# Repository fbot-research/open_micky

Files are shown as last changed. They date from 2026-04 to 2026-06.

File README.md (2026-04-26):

# [Open MICKY🤖](https://open-micky.readthedocs.io/en/latest/)

 

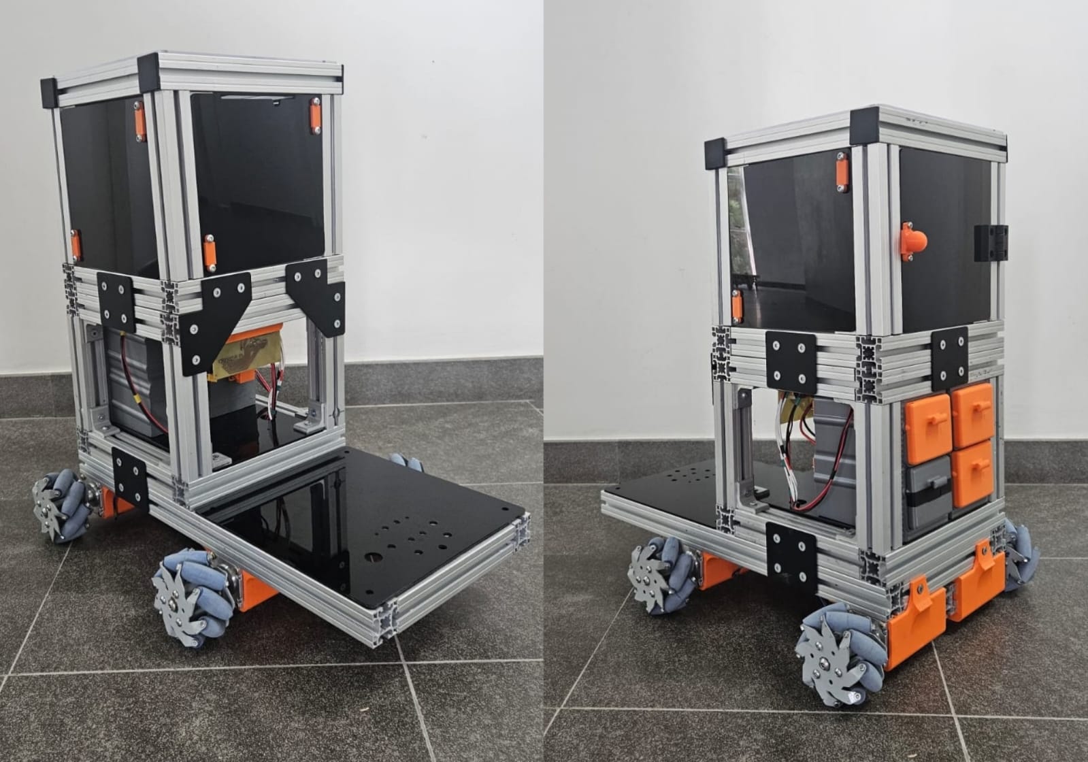
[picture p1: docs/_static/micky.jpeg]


 

---

## 💵 Total Cost 💵

> [!NOTE] 
> Cost excludes 3D printing, tools, shipping, and taxes.

| Price | BRL | EUR | USD |
|---|:---:|:---:|:---:|
| Structural Components | ~R$2103.18 | ~€458.66 | ~$1064.58 |
| Electrical System | ~R$902.4 | ~€406.47 | ~$200.81 |
| Locomotion System | ~R$2834.46 | ~€330.36 | ~$381.73 |
| **Total** | **~R$5840.04** | **~€1195.49** | **~$1647.12** |

---

## 🚀 Get Started 🚀

> [!NOTE] 
> If you are totally new to programming, please spend at least a day to get yourself familiar with basic Python, Ubuntu and Github (with the help of Google and AI). At least you should know how to setup ubuntu system, git clone, pip install, use intepreters (VS Code, Cursor, Pycharm, etc.) and directly run commands in the terminals.

1. 💵 **Buy your parts**: [Bill of Materials](https://open-micky.readthedocs.io/en/latest/hardware/getting_started/material.html)
2. 🖨️ **Print your parts**: [3D printing](https://open-micky.readthedocs.io/en/latest/hardware/getting_started/3d.html)
3. ⚒️ **Build your robot**: [Assembly](https://open-micky.readthedocs.io/en/latest/hardware/getting_started/assembly.html)
4. 💻 **Get it running**: [Software](https://open-micky.readthedocs.io/en/latest/software/index.html)

---

## 👥 Contributors

This project was developed by the FBOT Robotics Team.

**Main Contributors:**

- [Caio Paiva](https://github.com/CaioCPaiva) – Robot construction and 3D support design
- [Conrado Floriano](https://github.com/conradof) - Robot construction
- [Fernanda Oliveira](https://github.com/nanda0514) - Robot construction
- [Gabriel Torres](https://github.com/Gabrieltlt) - Documentation and website development
- [Henrique Vaz](https://github.com/Henrivaz) - Simulation development
- [Kauã Oliveira](https://github.com/KauaOliveira11) - Wheel control system and teleoperation
- [Patrick Meerssche](https://github.com/PatrickMeerssche) - Robot mechanical design
- [Pedro Paiva](https://github.com/pedromarchioretto) - Cost analysis

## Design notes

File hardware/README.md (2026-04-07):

# MICKY 3D Models

STL files for the Open MICKY robot.

---

## Upper Module



3D printed parts used in the robot's upper module.

---

## Lower Module



3D printed parts used in the robot's lower module.

---

## Base Module



3D printed parts used in the robot's base.

---

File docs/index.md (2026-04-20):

Open MICKY
===========

 

---

<div style="text-align: justify;">
  The high cost of commercial mobile robot platforms remains a significant barrier for teams entering competitive and research environments such as RoboCup@Work, particularly in regions with limited funding, such as Latin America. This barrier often restricts participation and slows down the development of new robotics solutions.

  MICKY was developed to address this challenge by providing a low-cost, open-source omnidirectional mobile base designed to be modular and mechanically capable. The platform follows a design philosophy similar to other accessible robotic bases, focusing on enabling new teams and researchers to enter the field of mobile robotics.

  The system adopts a modular architecture based on 40×40 T-slot aluminum extrusions combined with a Mecanum wheel drive system, enabling full holonomic motion while supporting significant payloads.
  
  Rather than relying on expensive proprietary solutions, MICKY is built using Commercial Off-The-Shelf (COTS) components and a simplified mechanical design. This approach enables a high payload-to-cost ratio while maintaining ease of assembly, maintenance, and customization.

  The platform is designed to support applications such as mobile manipulation, autonomous navigation, and robotics research, while allowing straightforward integration of sensors, actuators, and additional subsystems.

  Ultimately, MICKY aims to democratize access to mobile robotics by providing a scalable, reproducible, and economically viable platform for students, researchers, and robotics teams.
</div>



---

```{toctree}
:maxdepth: 2
:caption: Contents:

hardware/index
software/index
```

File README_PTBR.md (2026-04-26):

# [Open MICKY🤖](https://open-micky.readthedocs.io/en/latest/)

 



 

---

## 💵 Custo Total 💵

> [!NOTE] 
> O custo não inclui impressão 3D, ferramentas, frete e impostos.

| Preço | BRL | EUR | USD |
|---|:---:|:---:|:---:|
| Componentes Estruturais | ~R$2103.18 | ~€458.66 | ~$1064.58 |
| Sistema Elétrico | ~R$902.4 | ~€406.47 | ~$200.81 |
| Sistema de Locomoção | ~R$2834.46 | ~€330.36 | ~$381.73 |
| **Total** | **~R$5840.04** | **~€1195.49** | **~$1647.12** |

---

## 🚀 Começando 🚀

> [!NOTE] 
> Se você é totalmente iniciante em programação, recomendamos dedicar pelo menos um dia para se familiarizar com conceitos básicos de Python, Ubuntu e GitHub (com ajuda do Google ou ferramentas de IA). É importante saber configurar o sistema Ubuntu, utilizar comandos como `git clone` e `pip install`, usar ambientes de desenvolvimento (VS Code, Cursor, PyCharm, etc.) e executar comandos diretamente no terminal.

1. 💵 **Compre os componentes**: [Lista de Materiais](https://open-micky.readthedocs.io/pt-br/latest/hardware/getting_started/material.html)
2. 🖨️ **Imprima as peças**: [Impressão 3D](https://open-micky.readthedocs.io/pt-br/latest/hardware/getting_started/3d.html)
3. 🛠️ **Monte o robô**: [Montagem](https://open-micky.readthedocs.io/pt-br/latest/hardware/getting_started/assembly.html)
4. 💻 **Coloque em funcionamento**: [Software](https://open-micky.readthedocs.io/pt-br/latest/software/index.html)

---

## 👥 Contribuidores

Este projeto foi desenvolvido pela equipe de robótica FBOT.

**Principais Contribuidores:**

- [Caio Paiva](https://github.com/CaioCPaiva) – Construção do robô e modelagem dos suportes 3D  
- [Conrado Floriano](https://github.com/conradof) – Construção do robô  
- [Fernanda Oliveira](https://github.com/nanda0514) – Construção do robô  
- [Gabriel Torres](https://github.com/Gabrieltlt) – Documentação e desenvolvimento do site  
- [Henrique Vaz](https://github.com/Henrivaz) – Desenvolvimento da simulação  
- [Kauã Oliveira](https://github.com/KauaOliveira11) – Sistema de controle das rodas e teleoperação  
- [Patrick Meerssche](https://github.com/PatrickMeerssche) – Projeto mecânico do robô  
- [Pedro Paiva](https://github.com/pedromarchioretto) – Análise de custos

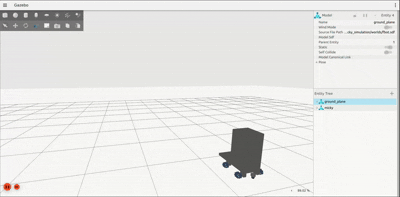
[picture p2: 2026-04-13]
docs/_static/videos/simulation_video.gif

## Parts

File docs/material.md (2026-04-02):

#  **Bill of Material**

##  Total Cost 

```{note}
Doesn't include cost of 3D printing, tools, shipping and taxes.
```

| Price | R$ | US | EU |
| --- | --- | --- | --- |
| Structural | ~R$949.62 | ~$184.16 | ~€158.78 |
| Motion System | ~R$3140 | ~$608.95 | ~€525.01 |
| Eletronics | ~R$1133.01 | ~$219.73 | ~€189.44 |
| **Total** | **~R$5222.63** | **~$1012.84** | **~€873.22** |

## Structural

| Part | Amount | Unit Cost (R$) | Buy (R$) |
| --- | --- | --- | --- |
| Placa Quadrada p/ Perfil Base 40 | 3 | ~R$17.46 | [Forseti](https://loja.forsetisolucoes.com.br/placa-de-conexao-montagem-lateral-quadrada-para-perfil-estrutural-em-aluminio) |
| Placa de Conexão T p/ Perfil Base 40 | 3 | ~R$26.78 | [Forseti](https://loja.forsetisolucoes.com.br/placa-de-conexao-montagem-t-para-perfil-estrutural-em-aluminio) |
| Porca Martelo Canal 8 - p/ Perfil Base 40 - M6 - 50un | 1 | ~R$83.16 | [Forseti](https://loja.forsetisolucoes.com.br/porca-t-martelo-para-perfil-estrututral-em-aluminio-canal-8-40-40x40-tslot-t-slot) |
| Placa de Conexão 90° - c/ Corte p/ Perfil 40 | 6 | ~R$27.94 | [Forseti](https://loja.forsetisolucoes.com.br/placa-de-conexao-montagem-90-graus-com-corte-para-perfil-estrutural-em-aluminio) |
| Perfil estrutural 40x40mm - CANAL 8 - 300mm | 6 | ~R$33.3 | [Forseti](https://loja.forsetisolucoes.com.br/perfil-estrutural-em-aluminio-40x40-basico-canal-8-t-slot-tslot) |
| Perfil estrutural 40x40mm CANAL 8 - 220mm | 15 | ~R$24.42 | [Forseti](https://loja.forsetisolucoes.com.br/perfil-estrutural-em-aluminio-40x40-basico-canal-8-t-slot-tslot) |

## Motion System

| Part | Amount | Unit Cost (R$) | Buy (R$) |
| --- | --- | --- | --- |
| Driver para Motor de Passo TB6600 | 6 | ~R$75 | [Robocore](https://www.robocore.net/driver-motor/driver-para-motor-de-passo-tb6600) |
| Motor de Passo Nema 23 – Torque 30 kgf (EIXO 21mm x 8mm) | 6 | ~R$215 | [Tecmaf](https://loja.tecmaf.com.br/motores-de-passo-e-componentes-cnc/motor-de-passo/motor-de-passo-nema-23-30kgf-cm-749) |
| Conjunto de Rodas Mecanum MEC-100 | 1 | ~R$1400 | [Celusinagem](https://celusinagem.wixsite.com/omni-mecanum) |

```{note}
We opted to manufacture the wheels through a local supplier, as this proved to be significantly more profitable than purchasing them online.
```

## Electronics

| Part | Amount | Unit Cost (R$) | Unit Cost (US) | Unit Cost (EU) | Buy (R$) |
| --- | --- | --- | --- | --- | --- |
| 5-Conductor Lever-Nut Connector | 10 | R$3.50 | $0.68 | €0.59 | [Eletrogate](https://www.eletrogate.com/conector-wago-borne-emenda-para-5-fios) |
| XT60 60A Male/Female Power Connector Pair | 8 | R$6.70 | $1.28| €1.11 | [Eletrogate](https://www.eletrogate.com/conector-xt-60) |
| Heat Shrink Tubing Assortment Kit, 5 Colors, 328 Pieces | 1 | R$14.90 | $2.89 | €2.49 | [Eletrogate](https://www.eletrogate.com/kit-tubo-termo-retratil-com-328-unidades-em-5-cores) |
| Nickel-Plated Steel Strip for 18650 Battery Spot Welding (10 m × 8 mm)| 5 | R$30.93 | $6.00 | €5.18 | [Usainfo](https://www.usinainfo.com.br/ferramentas/fita-de-niquel-com-aco-para-soldar-baterias-18650-10-metros-x-8mm-8694.html) |
| Insulated Fork Terminals for 2.5 mm² Conductors (Blue, 100 pcs)| 1 | R$31.00 | $6.01 | €5.19 | [Casa do Eletricista](https://www.casadoeletricistasc.com.br/terminal-pre-isolado-garfo-para-cabo-2-5mm2-azul-100-unidades/p/kit197) |
| TP-Link UH700 7-Port USB 3.0 Powered Hub | 1 | R$229.90 | $44.6 | €38.49 | [Kabum](https://www.kabum.com.br/produto/129463/hub-tp-link-portatil-usb-3-0-de-7-portas-uh700) |

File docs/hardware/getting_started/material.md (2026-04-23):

# 🛒 Bill of Materials

<div style="text-align: justify;">

## Total Cost 

```{note}
Doesn't include cost of 3D printing, tools, shipping and taxes.
```

| Price | BRL | EUR | USD |
|---|:---:|:---:|:---:|
| Structural Components | ~R$2103.18 | ~€458.66 | ~$1064.58 |
| Electrical System | ~R$902.4 | ~€406.47 | ~$200.81 |
| Locomotion System | ~R$2834.46 | ~€330.36 | ~$381.73 |
| **Total** | **~R$5840.04** | **~€1195.49** | **~$1647.12** |

---

## Structural Components

| Part | Amount | Unit Cost (BRL) | Buy (R$) | Unit Cost (EUR) | Buy (€) | Unit Cost (USD) | Buy ($) |
|---|:---:|:---:|:---:|:---:|:---:|:---:|:---:|
| 40×40 T-Slot Aluminum Extrusion 600 mm | 2 | ~R$75.60 | [Forseti](https://loja.forsetisolucoes.com.br/perfil-estrutural-em-aluminio-40x40-basico-canal-8-t-slot-tslot) | ~€8.58 | [Motedis](https://www.motedis.com/en/Profile-40x40L-I-Type-slot-8) | ~$33.60 | [McMASTER-CARR](https://www.mcmaster.com/products/aluminum-extrusions/rail-height~40-mm/t-slotted-framing-rails-4/) |
| 40×40 T-Slot Aluminum Extrusion 300 mm | 8 | ~R$37.80 | [Forseti](https://loja.forsetisolucoes.com.br/perfil-estrutural-em-aluminio-40x40-basico-canal-8-t-slot-tslot) | ~€4.29 | [Motedis](https://www.motedis.com/en/Profile-40x40L-I-Type-slot-8) | ~$16.80 | [McMASTER-CARR](https://www.mcmaster.com/products/aluminum-extrusions/rail-height~40-mm/t-slotted-framing-rails-4/) |
| 40×40 T-Slot Aluminum Extrusion 220 mm | 15 | ~R$27.72 | [Forseti](https://loja.forsetisolucoes.com.br/perfil-estrutural-em-aluminio-40x40-basico-canal-8-t-slot-tslot) | ~€3.37 | [Motedis](https://www.motedis.com/en/Profile-40x40L-I-Type-slot-8) | ~$12.32 | [McMASTER-CARR](https://www.mcmaster.com/products/aluminum-extrusions/rail-height~40-mm/t-slotted-framing-rails-4/) |
| 40×40 T-Slot Aluminum Extrusion 180 mm | 4 | ~R$22.68 | [Forseti](https://loja.forsetisolucoes.com.br/perfil-estrutural-em-aluminio-40x40-basico-canal-8-t-slot-tslot) | ~€2.76 | [Motedis](https://www.motedis.com/en/Profile-40x40L-I-Type-slot-8) | ~$10.08 | [McMASTER-CARR](https://www.mcmaster.com/products/aluminum-extrusions/rail-height~40-mm/t-slotted-framing-rails-4/) |
| 40×40 T-Slot Aluminum Extrusion 75 mm | 2 | ~R$10.08 | [Forseti](https://loja.forsetisolucoes.com.br/perfil-estrutural-em-aluminio-40x40-basico-canal-8-t-slot-tslot) | ~€1.15 | [Motedis](https://www.motedis.com/en/Profile-40x40L-I-Type-slot-8) | ~$4.20 | [McMASTER-CARR](https://www.mcmaster.com/products/aluminum-extrusions/rail-height~40-mm/t-slotted-framing-rails-4/) |
| L-Bracket | 38 | ~R$4.77 | [Forseti](https://loja.forsetisolucoes.com.br/cantoneira-38x38x28mm-em-aluminio-p-perfis-base-30-40-45-50-t-slot-tslot) | ~€1.10 | [Motedis](https://www.motedis.com/en/Bracket-Alu-anodized-40x40) | ~$5.14 | [80/20](https://8020.net/40-4302.html) |
| Profile End Cap | 18 | ~R$2.47 | [Forseti](https://loja.forsetisolucoes.com.br/capa-de-fechamento-frontal-quadrada-preta-para-perfil-estrutural-em-aluminio) | ~€0.47 | [Motedis](https://www.motedis.com/en/Cover-Caps-40x40-I-Type-Slot-8) | ~$0.76 | [Motedis-USA](https://www.motedis-usa.com/en/Cover-Caps-40x40-I-Type-Slot-8) |
| Square Connector Plate 40×40 | 3 | ~R$10.95 | [Forseti](https://loja.forsetisolucoes.com.br/placa-de-conexao-montagem-lateral-quadrada-para-perfil-estrutural-em-aluminio) | ~€2.57 | [Motedis](https://www.motedis.com/en/Square-connector-plate-76x76x5-Lasercut) | ~$4.17 | [Motedis-USA](https://www.motedis-usa.com/en/Square-connector-plate-76x76x5-Lasercut) |
| L Connector Plate 40×40 | 2 | ~R$21.27 | [Forseti](https://loja.forsetisolucoes.com.br/placa-de-conexao-montagem-90-graus-com-corte-para-perfil-estrutural-em-aluminio) | ~€3.82 | [Motedis](https://www.motedis.com/en/-L-connector-plate-Alu-elox-4040) | ~$6.21 | [Motedis-USA](https://www.motedis-usa.com/en/-L-connector-plate-Alu-elox-4040?show_cart=1&from_cart=1&products_id=9999910079) |
| T Connector Plate 40×40 | 1 | ~R$13.15 | [Forseti](https://loja.forsetisolucoes.com.br/placa-de-conexao-montagem-t-para-perfil-estrutural-em-aluminio) | ~€4.49 | [Motedis](https://www.motedis.com/en/Connector-plate-T-Alu-elox-4040) | ~$7.29 | [Motedis-USA](https://www.motedis-usa.com/en/Connector-plate-T-Alu-elox-4040) |
| M6 x 12 mm Countersunk Allen Screw | 160 | ~R$0.86 | [Forseti](https://loja.forsetisolucoes.com.br/parafuso-allen-cabeca-conica-escareada-m6) | ~€0.34 | [Motedis](https://www.motedis.com/en/countersunk-screw-with-hexagon-socket-according-to-DIN-7991) | ~$0.63 | [80/20](https://8020.net/13-6712.html) |
| M6 x 20 mm Countersunk Allen Screw | 4 | ~R$0.86 | [Forseti](https://loja.forsetisolucoes.com.br/parafuso-allen-cabeca-conica-escareada-m6) | ~€0.33 | [Motedis](https://www.motedis.com/en/countersunk-screw-with-hexagon-socket-according-to-DIN-7991) | ~$0.85 | [80/20](https://8020.net/11-6720.html) |
| M4 x 20 mm Countersunk Allen Screw | 12 | ~R$0.32 | [Parafuso Fácil](https://www.parafusofacil.com.br/parafuso-allen/parafuso-allen-chato/din-7991-parafuso-allen-chato-ma-4-x-20-inox-304-a2-classe-70-passivado/) | ~€0.32 | [Motedis](https://www.motedis.com/en/countersunk-screw-with-hexagon-socket-according-to-DIN-7991) | ~$0.52 | [Motedis-USA](https://www.motedis-usa.com/en/countersunk-screw-with-hexagon-socket-according-to-DIN-7991) |
| M4 x 12 mm Countersunk Allen Screw | 18 | ~R$0.11| [Parafuso Fácil](https://www.parafusofacil.com.br/parafuso-allen/parafuso-allen-chato/din-7991-parafuso-allen-chato-ma-4-x-12-aco-liga-classe-10-9-enegrecido-de-tempera-1/) | ~€0.32 | [Motedis](https://www.motedis.com/en/countersunk-screw-with-hexagon-socket-according-to-DIN-7991) | ~$0.69 | [80/20](https://8020.net/11-4712.html) |
| M6 x 35 mm Motor Mount Screw | 16 | ~R$1.72 | [Forseti](https://loja.forsetisolucoes.com.br/parafuso-allen-cabeca-abaulada-panela-m6) | ~€0.39 | [Motedis](https://www.motedis.com/en/countersunk-screw-with-hexagon-socket-according-to-DIN-7991) | ~$0.63 | [Motedis-USA](https://www.motedis-usa.com/en/countersunk-screw-with-hexagon-socket-according-to-DIN-7991) |
| M6 T-Nut | 130 | ~R$2.08 | [Forseti](https://loja.forsetisolucoes.com.br/porca-t-martelo-para-perfil-estrututral-em-aluminio-canal-8-40-40x40-tslot-t-slot) | ~€0.50 | [Motedis](https://www.motedis.com/en/T-nut-B-type-slot-8-M6-stainless-steel) | ~$1.19 | [80/20](https://8020.net/13119.html) |
| M6 Hex Nut | 34 | ~R$0.57 | [Forseti](https://loja.forsetisolucoes.com.br/porca-sextavada-m3-m4-m5-m6-m8-m10-m12) | ~€0.30 | [Motedis](https://www.motedis.com/en/Nut-DIN-439-M4-M5-M6-M8-M10-and-M12) | ~$0.14 | [80/20](https://8020.net/3820.html) |
| M4 Hex Nut | 56 | ~R$0.57 | [Forseti](https://loja.forsetisolucoes.com.br/porca-sextavada-m3-m4-m5-m6-m8-m10-m12) | ~€0.30 | [Motedis](https://www.motedis.com/en/Nut-DIN-439-M4-M5-M6-M8-M10-and-M12) | ~$0.19 | [80/20](https://8020.net/11-4065.html) |
| Copper Sheet 30 × 20 cm | 2 | ~R$29.70 | [UsinaInfo](https://www.usinainfo.com.br/placa-de-fenolite/placa-de-fenolite-cobreada-simples-15x30-cm-para-circuito-impresso-3845.html) | ~€11.65 | [LinGold](https://lingold.pt/copper-sheet/copper-sheet-15-mm) | ~$5.20 | [MCTInfo](https://mctinfo.net/products/copper-clad-laminate-fr4) |
| Acrylic Sheet 1 m × 1.3 m | 1 | ~R$253.16 | [AcriLoja](https://www.acriloja.com/placa-chapa-acrilico/preto/2mm/placa-de-acrilico-preto-100cm-x-150cm-espessura-2mm-chapa-de-acrilico) | ~€86.33 | [Plastic Sheets Shop](https://plasticsheetsshop.co.uk/product/frosted-black-acrylic-sheet-3-mm/) | ~$74.80 | [ACPlasticsInc](https://www.acplasticsinc.com/products/2025-060-48x-72-trucast-p) |

---

## Electrical System

| Part | Amount | Unit Cost (BRL) | Buy (R$) | Unit Cost (EUR) | Buy (€) | Unit Cost (USD) | Buy ($) |
|---|:---:|:---:|:---:|:---:|:---:|:---:|:---:|
| Hoverboard Battery (36V) | 4 | ~R$139.30 | [Arco Iris LED](https://www.arcoirisled.com.br/produto/bateria-original-para-hoverboard-eletrico-36v-44ah-ydtech) | ~€89.99 | [Decathlon](https://www.decathlon.ie/p/1100365324-2495102-36v-4ah-hoverboard-battery-replacement.html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) | ~$44.99 | [BatteryGC](https://batterygc.com/products/10s2p-36v-4-4ah-18650-li-ion-battery-for-hoverboard-scooter-balance-board-car) |
| Ferrule Terminals (Wire Ferrules) | 20 | ~R$14.69 | [Santil](https://www.santil.com.br/terminal-ilhos-pre-isolado-cinza-simples-4mm-com-100-pecas-eletrokit/p) | ~€0.086 | [Mouser](https://eu.mouser.com/ProductDetail/KS-Terminals/EN2508?qs=%252B6g0mu59x7IZJehitj7%252BJA%3D%3D) | ~$0.014 | [FerrulesDirect](https://www.ferrulesdirect.com/collections/insulated-wire-ferrules/products/ad15006) |
| 20A Switch | 3 | ~R$7.50 | [Casa do Resistor](https://www.casadoresistor.com.br/chave-kcd4-201-4t-16-20a-125-250v-preta) | ~€5.6 | [Hestore](https://www.hestore.eu/prod_10040377.html#) | ~$3.15 | [McMASTRER-CARR](https://www.mcmaster.com/products/7395k111/) |
| Emergency Stop Button (Mushroom Type) | 1 | ~R$28.90 | [OnEletrica](https://www.oneletrica.com.br/botao-emergencia-22mm-gira-destrava-com-2-contatos-nf) | ~€27.99 | [Conrad](https://www.conrad.com/en/p/schneider-electric-xb5as8442-kill-switch-epo-switch-front-ring-steel-kill-switch-round-reset-function-lockable-1-1983552.html) | ~$11.12 | [RS](https://us.rs-online.com/product/altech-corp/2am4/70156810/) |

```{important}
Use a 2 mm² flexible cable (approximately AWG 14) for power distribution.
```

---

## Locomotion System

| Part | Amount | Unit Cost (BRL) | Buy (R$) | Unit Cost (EUR) | Buy (€) | Unit Cost (USD) | Buy ($) |
|---|:---:|:---:|:---:|:---:|:---:|:---:|:---:|
| NEMA 23 Stepper Motor (30 kgf·cm) | 4 | ~R$215.00 | [Tecmaf](https://loja.tecmaf.com.br/motores-de-passo-e-componentes-cnc/motor-de-passo/motor-de-passo-nema-23-30kgf-cm-749) | ~€21.24 | [Cloudray](https://www.cloudraylaser.com/products/cloudray-102mm-3n-m-5a-2-phase-nema23-open-loop-stepper-motor) | ~$28.70 | [StepperOnline](https://www.omc-stepperonline.com/nema-23-bipolar-3nm-425oz-in-8mm-diameter-4-2a-57x57x113mm-4-wires-stepper-motor-23hs45-4204s1) |
| TB6600 Stepper Driver | 4 | ~R$79.90 | [RoboCore](https://www.robocore.net/driver-motor/driver-para-motor-de-passo-tb6600) | ~€11.95 | [Otronic](https://www.otronic.nl/en/tb6600-stepper-motor-driver-for-nema-17-23-34-9-42.html) | ~$20.00 | [DFRobot](https://www.dfrobot.com/product-1547.html) |
| MPU-9250 IMU with BMP280 (6-pin) | 2 | ~R$127.43 | [Elecbee](https://www.elecbee.com/en/product-detail/mpu9250-bmp280-10dof-gy-91-acceleration-gyroscope-compass-nine-shaft-sensor-module_25515) | ~€22.89 | [Elecbee](https://www.elecbee.com/en/product-detail/mpu9250-bmp280-10dof-gy-91-acceleration-gyroscope-compass-nine-shaft-sensor-module_25515) | ~$23.38 | [Elecbee](https://www.elecbee.com/en/product-detail/mpu9250-bmp280-10dof-gy-91-acceleration-gyroscope-compass-nine-shaft-sensor-module_25515) |
| 100mm Mecanum Wheel | 1 | ~R$1400.00 | [CelUsinagem](https://celusinagem.wixsite.com/omni-mecanum) | ~€151.82 | [RobotShop](https://eu.robotshop.com/products/100mm-mecanum-wheel-set) | ~$140.17 | [RobotShop](https://www.robotshop.com/products/100mm-mecanum-wheel-set) |

```{note}
We opted to manufacture the wheels through a local supplier, as this proved to be significantly more cost-effective than purchasing them online. For reference, links to similar wheels available on the market are provided above.
```

---

## 3D Printed Parts

The following table lists all required 3D printed components.

| Module | Part | Quantity | STL Link |
|---|:----:|:---:|:---:|
| Structural | Door Handle| 1 | [STL](https://github.com/fbot-research/open_micky/blob/main/hardware/structural/door_handle.stl) |
| Structural | Door Handle Magnet | 1 | [STL](https://github.com/fbot-research/open_micky/blob/main/hardware/structural/door_handle_magnet.stl) |
| Structural | Side Acrylic Magnet | 6 | [STL](https://github.com/fbot-research/open_micky/blob/main/hardware/structural/side_acrylic_magnet.stl) |
| Structural | Side Acrylic Magnet Mount | 6 | [STL](https://github.com/fbot-research/open_micky/blob/main/hardware/structural/side_acrylic_magnet_mount.stl) |
| Battery | Battery Case Lower | 4 | [STL](https://github.com/fbot-research/open_micky/blob/main/hardware/battery/battery_case_female_socket_mount.stl) |
| Battery | Battery Case Upper | 4 | [STL](https://github.com/fbot-research/open_micky/blob/main/hardware/battery/battery_case_lower.stl) |
| Battery | Battery Case Female Socket Mount | 4 | [STL](https://github.com/fbot-research/open_micky/blob/main/hardware/battery/battery_case_upper.stl) |
| Battery | Battery Hotswap Connector | 2 | [STL](https://github.com/fbot-research/open_micky/blob/main/hardware/battery/battery_hotswap_connector.stl) |
| Battery | Battery Hotswap Male Connector | 4 | [STL](https://github.com/fbot-research/open_micky/blob/main/hardware/battery/battery_hotswap_male_connector.stl) |
| Drivers | Arduino Board Mount | 1 | [STL](https://github.com/fbot-research/open_micky/blob/main/hardware/drivers/arduino_PCB_support.stl) |
| Drivers | Driver Board Left Mount | 1 | [STL](https://github.com/fbot-research/open_micky/blob/main/hardware/drivers/driver_PCB_left_support.stl) |
| Drivers | Driver Board Right Mount | 1 | [STL](https://github.com/fbot-research/open_micky/blob/main/hardware/drivers/driver_PCB_right_support.stl) |
| Drivers | PCB's Support | 1 | [STL](https://github.com/fbot-research/open_micky/blob/main/hardware/drivers/PCBs_support.stl) |
| Drivers | Drivers Mount | 4 | [STL](https://github.com/fbot-research/open_micky/blob/main/hardware/drivers/drivers_support.stl) |
| Motors | Front Motor Mount | 2 | [STL](https://github.com/fbot-research/open_micky/blob/main/hardware/motors/front_motor_mount.stl) |
| Motors | Rear Motor Mount Left | 1 | [STL](https://github.com/fbot-research/open_micky/blob/main/hardware/motors/rear_motor_mount_left.stl) |
| Motors | Rear Motor Mount Right | 1 | [STL](https://github.com/fbot-research/open_micky/blob/main/hardware/motors/rear_motor_mount_right.stl) |
| Emergency | Emergency Stop Button Mount | 1 | [STL](https://github.com/fbot-research/open_micky/blob/main/hardware/emergency_button/emergency_button.stl) |

</div>

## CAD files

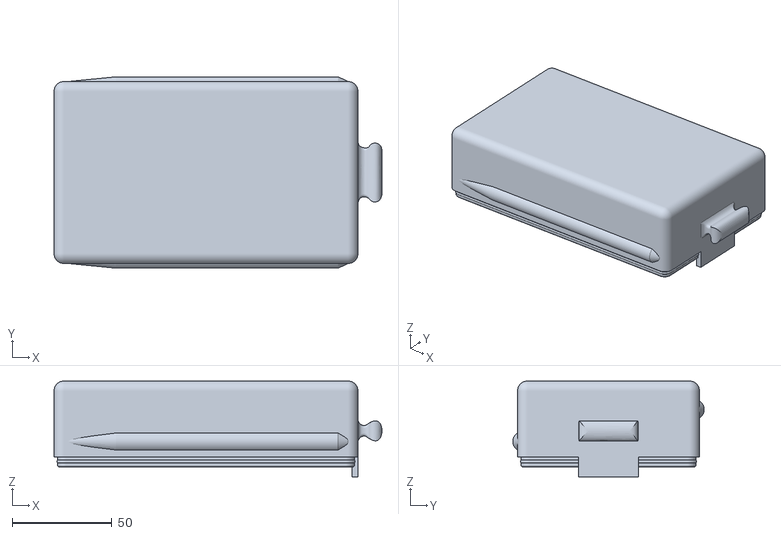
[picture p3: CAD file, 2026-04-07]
hardware/battery/battery_case_upper.stl
164.0 x 95.7 x 48.0

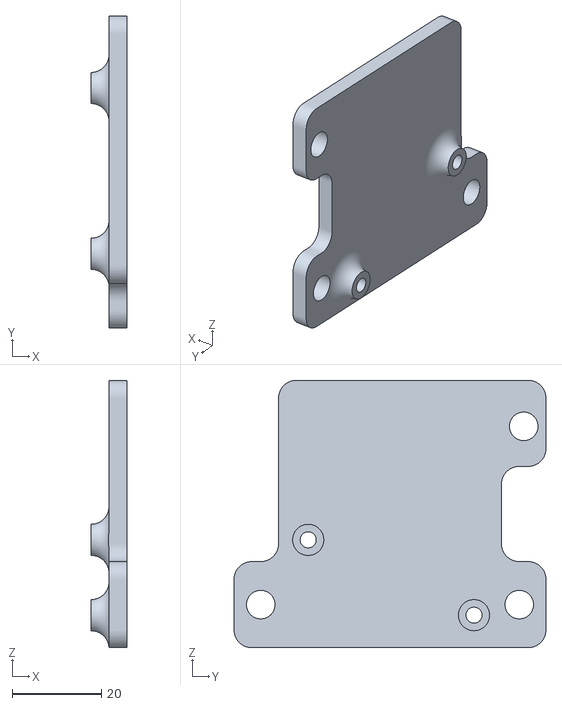
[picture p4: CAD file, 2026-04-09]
hardware/drivers/driver_PCB_left_support.stl
8.00 x 70.0 x 60.0

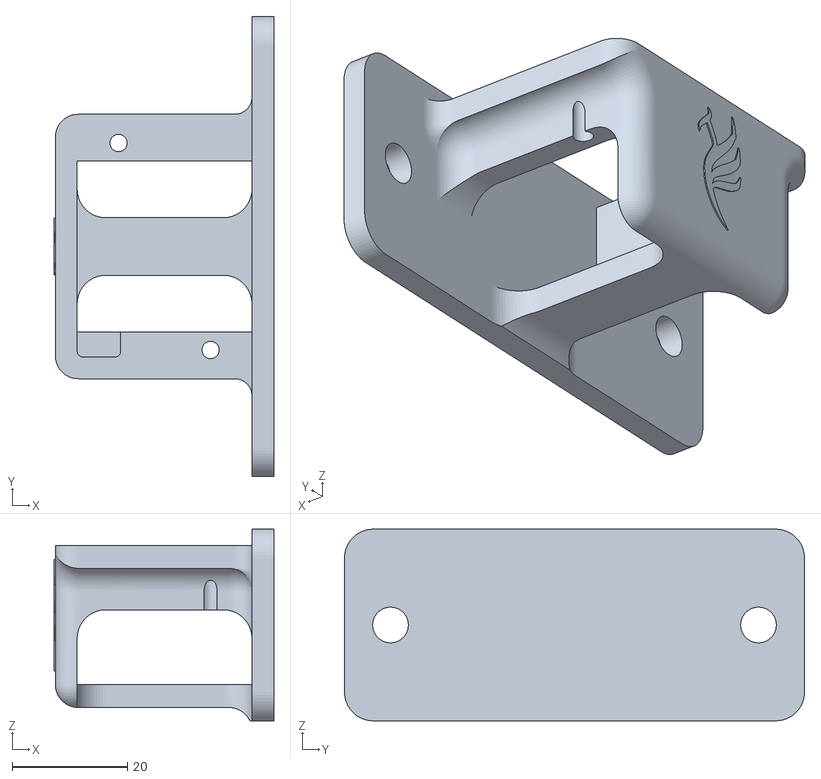
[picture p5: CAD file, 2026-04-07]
hardware/emergency_button/emergency_button.stl
38.2 x 80.0 x 33.3

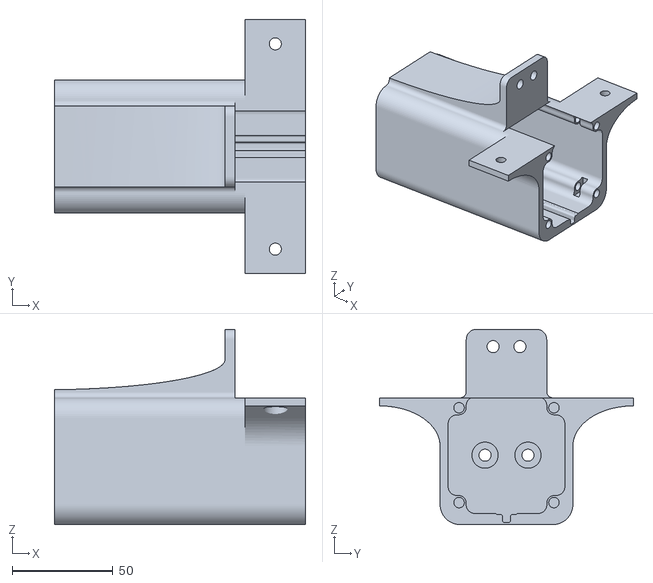
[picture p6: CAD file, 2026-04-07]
hardware/motors/front_motor_mount.stl
124.7 x 126.0 x 97.0

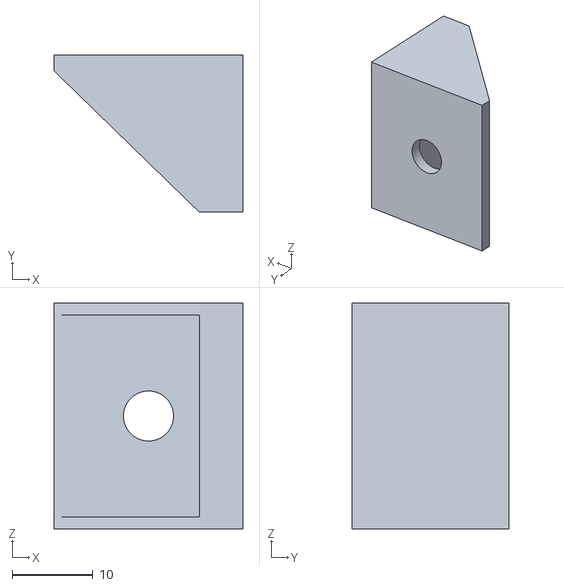
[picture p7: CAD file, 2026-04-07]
hardware/structural/side_acrylic_magnet.stl
23.4 x 19.5 x 28.0

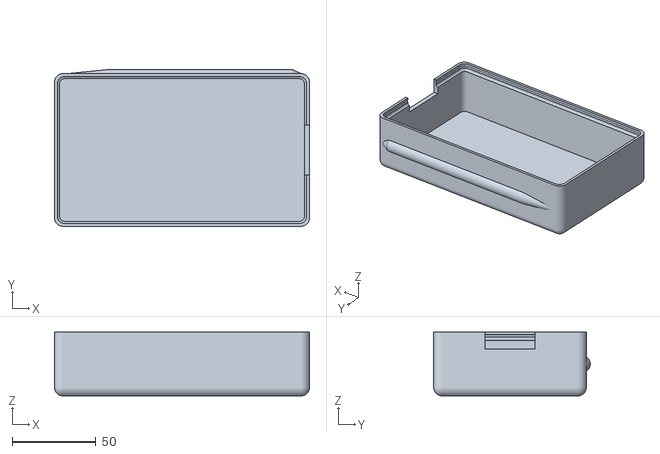
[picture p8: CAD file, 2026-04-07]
hardware/battery/battery_case_lower.stl
152.0 x 93.4 x 38.0

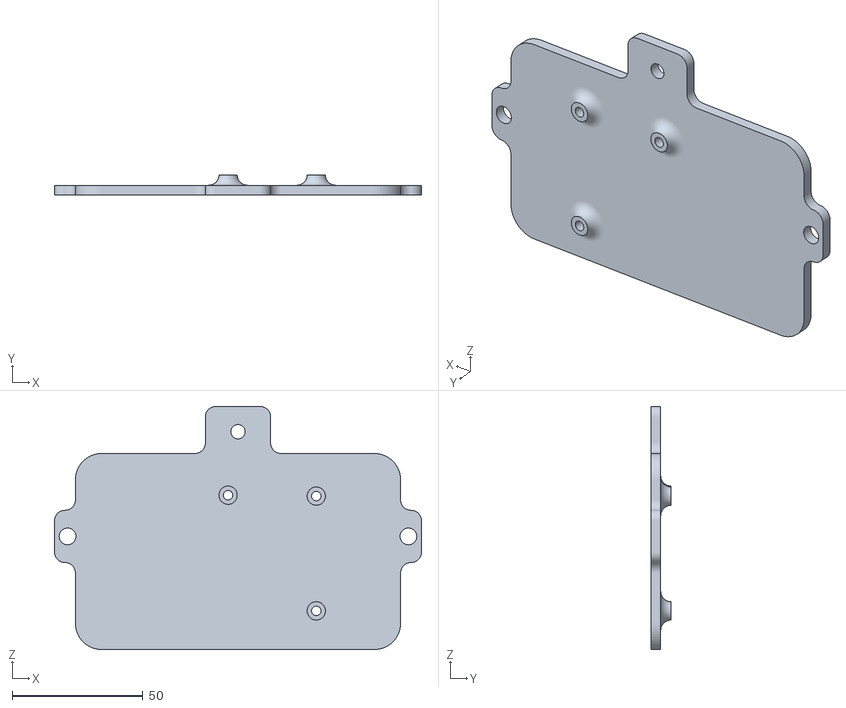
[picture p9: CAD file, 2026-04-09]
hardware/drivers/arduino_PCB_support.stl
140.4 x 7.80 x 93.0

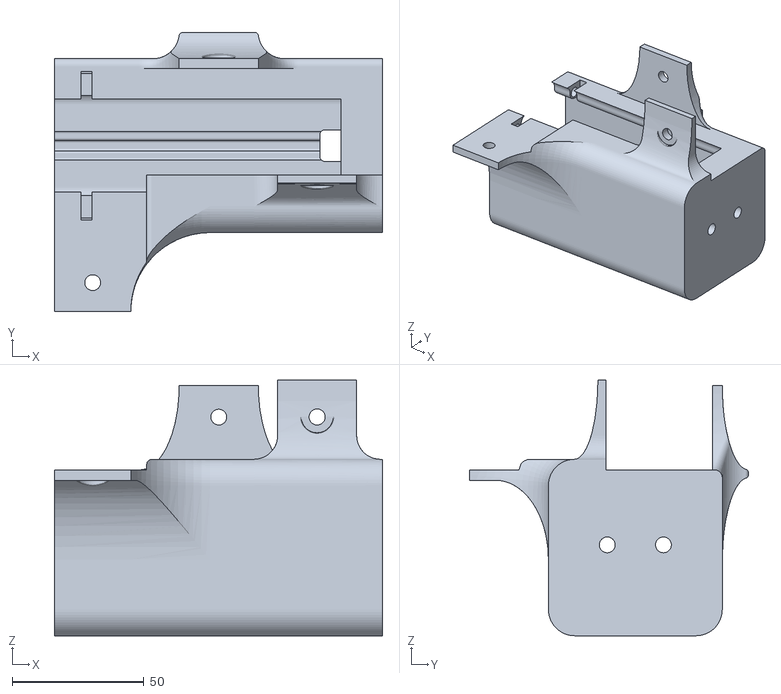
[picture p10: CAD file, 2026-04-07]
hardware/motors/rear_motor_mount_right.stl
124.5 x 106.0 x 97.0

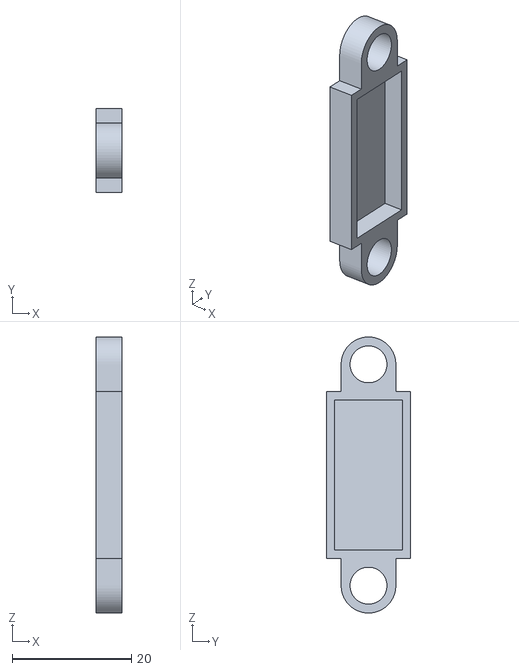
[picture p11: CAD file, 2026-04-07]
hardware/structural/side_acrylic_magnet_mount.stl
4.30 x 14.2 x 46.4

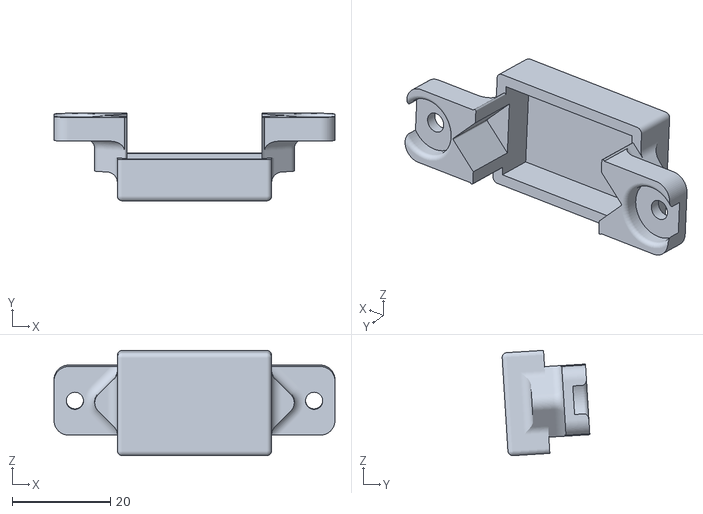
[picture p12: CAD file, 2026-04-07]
hardware/battery/battery_hotswap_male_connector.stl
57.2 x 17.8 x 21.4

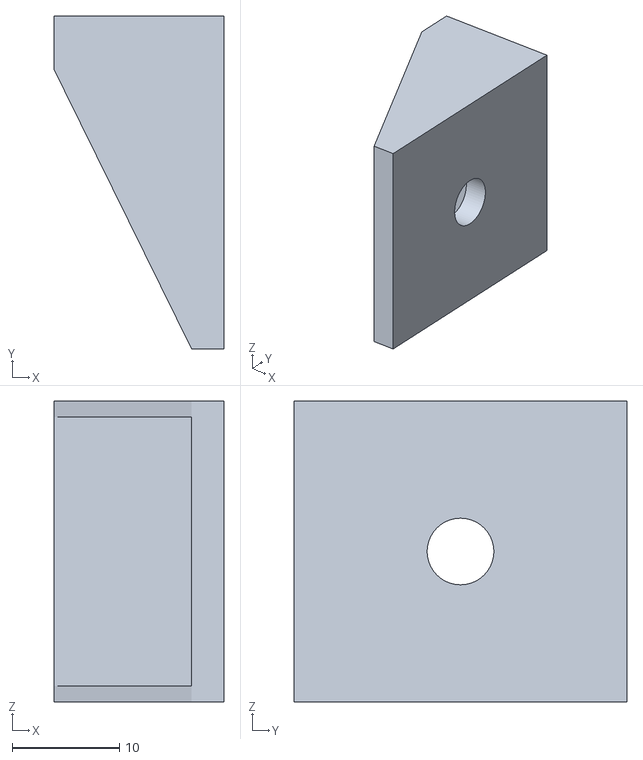
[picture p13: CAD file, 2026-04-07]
hardware/structural/door_handle_magnet.stl
15.8 x 31.0 x 28.0

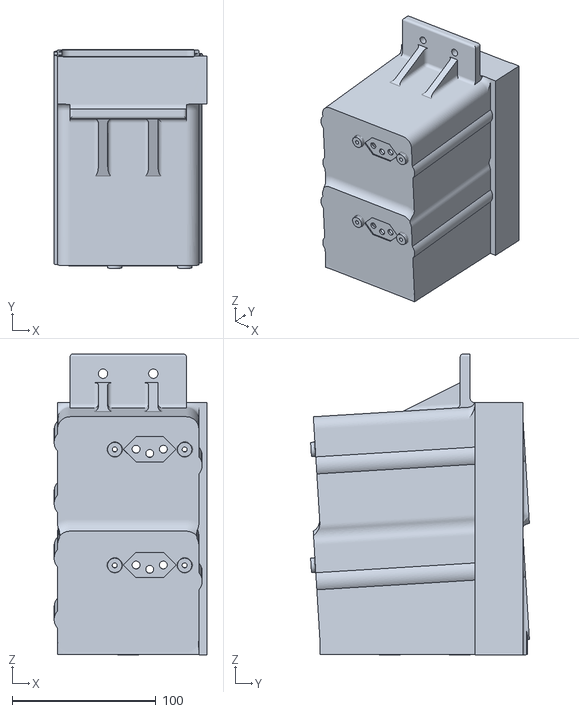
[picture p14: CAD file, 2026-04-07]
hardware/battery/battery_hotswap_connector.stl
106.4 x 152.4 x 209.7

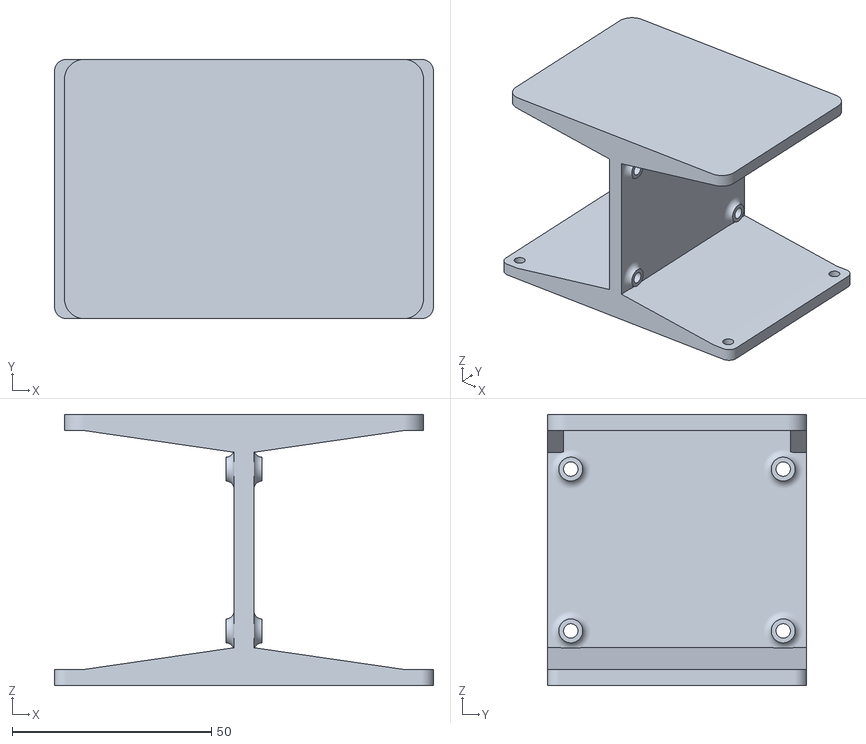
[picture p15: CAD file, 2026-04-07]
hardware/drivers/PCBs_support.stl
95.0 x 65.0 x 68.0

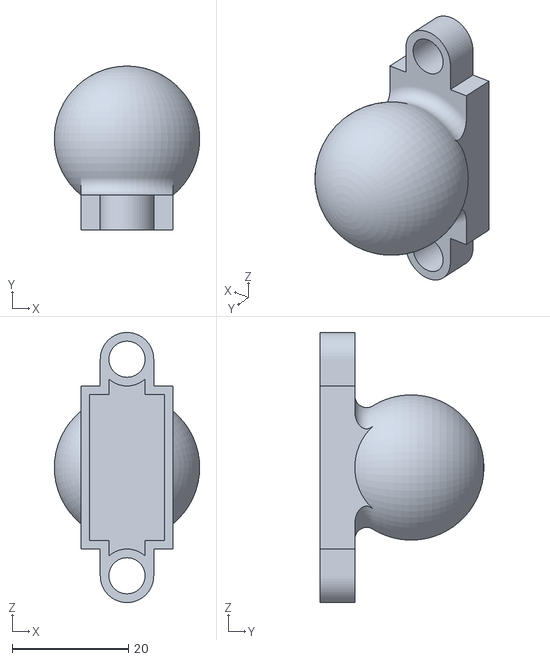
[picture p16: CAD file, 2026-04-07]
hardware/structural/door_handle.stl
25.0 x 28.2 x 46.4

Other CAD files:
hardware/drivers/driver_PCB_right_support.stl
hardware/motors/rear_motor_mount_left.stl
hardware/battery/battery_case_female_socket_mount.stl
hardware/drivers/drivers_support.stl

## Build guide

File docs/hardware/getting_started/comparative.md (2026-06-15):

# 📊 Comparative Analysis

<div style="text-align: justify;">

## Introduction

The development of low-cost and accessible robotic platforms remains a critical challenge for teams entering competitive and research-oriented environments such as RoboCup@Industrial, particularly in regions with limited funding such as Latin America. High costs associated with commercial mobile bases often create a significant barrier to entry, restricting participation and slowing down innovation.

In this context, we present the MICKY mobile base, an omnidirectional robotic platform specifically designed to reduce this barrier by prioritizing cost-efficiency without compromising mechanical capability. The platform adopts a modular architecture based on industrial 40x40 mm aluminum profiles and a Mecanum wheel drive system, enabling holonomic motion and supporting substantial payloads.

Rather than relying on expensive proprietary solutions, MICKY is built using Commercial Off-The-Shelf (COTS) components and a simplified mechanical design. This approach allows the platform to achieve a high payload-to-cost ratio while remaining accessible, maintainable, and adaptable to different use cases.

The system is designed to support mobile manipulation, autonomous navigation, and general-purpose robotics research, while allowing straightforward integration of sensors, actuators, and additional subsystems. Its modularity ensures that the platform can evolve according to the needs of each team.

This work also presents a comparative analysis between MICKY and other omnidirectional mobile bases, emphasizing its efficiency in terms of cost versus payload. The results highlight its position as a competitive and accessible alternative for teams seeking high mechanical performance under budget constraints.

Ultimately, the goal of this project is to democratize access to mobile robotics by providing a scalable, reproducible, and economically viable platform for new teams and researchers.

---

## 1. Technical Characterization of the MICKY Base

The MICKY base features a structure built from industrial 40×40 mm aluminum profiles combined with a Mecanum wheel drive system. Although the hardware includes six motors, the control architecture utilizes four active motors for locomotion.

To provide transparency regarding the platform's cost-efficiency, the total Bill of Materials (BOM) is broken down by functional subsystem in Table 1. 

**Table 1: Detailed Component Cost Breakdown**

| Subsystem | Components | Estimated Cost (USD) |
| :--- | :--- | :--- |
| **Structural** | 40×40 mm aluminum profiles, brackets, fasteners, custom plates | ~$250.00 |
| **Locomotion** | 4× MEC-100 Mecanum Wheels (100 mm), hubs, mechanical couplings | ~$185.00 |
| **Actuators** | 4× NEMA 23 stepper motors (30 kgf·cm) + 2 spare motors | ~$210.00 |
| **Control & Electronics** | Motor drivers, microcontrollers/SBC, wiring, emergency stop | ~$450.00 |
| **Power System** | Battery pack, Battery Management System (BMS), step-down modules | ~$250.00 |
| **Sensors** | 2D LiDAR, basic odometry sensors | ~$302.12 |
| **Total (BOM)** | | **~$1647.12** |

- **Operational Payload:** 32.55 kg
- **Actuators (Active):** 4× NEMA 23 stepper motors with 30 kgf·cm torque each
- **Wheels:** Mecanum MEC-100 set (100 mm diameter), with a nominal capacity of 15 kg per wheel
- **Structure:** Modular chassis using 40×40 mm aluminum profiles (Slot 8)

<div align="center">
<video width="40%" controls>
  <source src="../../_static/videos/payload_test.mp4" type="video/mp4">
</video>
</div>

*Experimental payload validation: MICKY transporting a 20 L load (~20 kg), demonstrating stable locomotion under real-world conditions.*

With a traction force of 24 kgf for a payload of 32.55 kg (plus a base mass of ~25 kg), the platform operates with a **traction-to-total weight ratio of approximately 0.41**, ensuring stability during lateral maneuvers without step loss under moderate accelerations.

---

## 2. Comparative Table: Omnidirectional Bases

Below is a compilation of technical data for the requested platforms, including low-cost models and industrial reference systems.

**Selection Criteria:** The benchmarked robots were chosen to represent a diverse cross-section of the Commercial Off-The-Shelf (COTS) omnidirectional market. This selection spans entry-level educational platforms (Wheeltec R550, myAGV), mid-range research vehicles (Mecabot Pro, SuperDroid IG52), and high-end industrial/research standards (TIAGo OMNI Base, TidyBot++). Evaluating these distinct tiers enables a rigorous assessment of MICKY's payload-to-cost efficiency against solutions built for varying funding constraints and application scales. Technical data and retail prices were sourced directly from the respective manufacturers' official datasheets and academic literature [1]-[5].

| Model (Label) | Payload (kg) | Cost (USD) | Drive Type | Efficiency ($/kg) |
|---|:---:|:---:|:---:|:---:|
| MICKY | 32.55 | ~$1647.12 | Mecanum (4-wheel drive) | $50.60 |
| Wheeltec R550 [1] | 15.00 | ~$532 | Mecanum (4-wheel drive) | $35.46 |
| myAGV 2023 Pi [2] | 5.00 | ~$949 | Mecanum (planetary) | $189.80 |
| Mecabot Pro | 22.00 | ~$6,918 | Mecanum (with suspension) | $314.45 |
| SuperDroid IG52 [3] | 90.00 | ~$3,750 | Mecanum (chain-driven) | $41.66 |
| AGV Pro | 50.00 | ~$6,000* | Mecanum/Omni | $120.00 |
| TIAGo OMNI Base [4] | 100.00 | ~$15,000* | Mecanum (industrial) | $150.00 |
| TidyBot++ [5] | 90.00 | ~$10,000* | Powered casters | $111.11 |

---

## 3. Cost vs. Payload Analysis

To rigorously evaluate the economic viability of the MICKY platform, a structured cost analysis was conducted based on a comprehensive and fully traceable Bill of Materials (BOM), openly available in the [project's official documentation](https://open-micky.readthedocs.io/en/latest/hardware/getting_started/material.html). By strategically integrating Commercial Off-The-Shelf (COTS) components with locally manufactured structural profiles, the total hardware cost was constrained to approximately \$1,647.12 USD. 

The relationship between cost and payload capacity, derived from quantitative experimental validation, is illustrated in the scatter plot below. The results demonstrate that MICKY achieves a highly competitive efficiency of \$50.60/kg, successfully bridging the gap between low-cost educational platforms and high-end industrial systems. Furthermore, while the use of a direct-driven Mecanum architecture introduces known mechanical limitations—such as vertical vibration on uneven surfaces and a restricted maximum velocity and acceleration compared to continuously steered wheels—this cost-to-payload metric confirms that higher payload capabilities can be decoupled from prohibitive system costs without compromising fundamental holonomic performance.

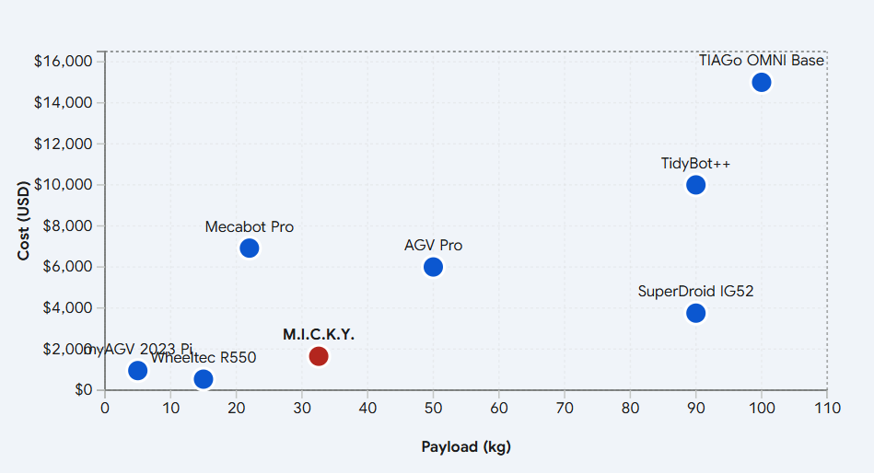
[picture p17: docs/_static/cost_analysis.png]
Graph


### 3.1 MICKY Positioning Discussion

The analysis reveals that MICKY occupies an **Efficiency Anomaly** niche.

- **MICKY vs. myAGV 2023 Pi:** While the cost is higher (~$1647 vs $949), MICKY delivers **6.5× more payload** (32.55 kg vs 5 kg). This highlights a significantly better cost-to-performance ratio in practical applications.

- **MICKY vs. Mecabot Pro:** Mecabot Pro costs over four times more, yet its payload is **32% lower (22 kg)**. MICKY demonstrates that higher mechanical traction capacity can be achieved using industrial COTS components at a fraction of the cost.

### 3.2 The Industrial Challenge: TIAGo OMNI Base and SuperDroid

These platforms represent the upper limits of payload capacity.

- **TIAGo OMNI Base:** It is a benchmark in service robotics design. With 207 mm wheels and industrial-grade motors, it supports a 100 kg payload. MICKY achieves **~32% of this payload at ~11% of the cost**, making it a viable alternative for budget-constrained laboratories.

- **SuperDroid IG52:** Achieves payloads of 90 kg through a chain reduction system (10:15). While effective for heavy loads, the chain system requires lubrication and tension adjustment, whereas MICKY’s direct coupling reduces mechanical maintenance.

---

## 4. References

[1] Dongguan Wheeltec Intelligent Technology Co., Ltd. "WHEELTEC R550 Omnidirectional ROS Robot Technical Specifications."  
[2] Elephant Robotics. "myAGV 2023 Pi Specifications - Mobile Chassis Autonomous Navigation." [Online]. Available: https://www.elephantrobotics.com/en/myagv-2023-pi-specifications-en/  
[3] SuperDroid Robots. "IG52 Mecanum Robot Platform Technical Datasheet."  
[4] PAL Robotics. "TIAGo OMNI Base - Innovation in every direction, Technical Specifications." [Online]. Available: https://pal-robotics.com/robot/tiago-omni-base/  
[5] Princeton University / Stanford University, "TidyBot++: Open-source Omnidirectional Mobile Base Specifications."

</div>

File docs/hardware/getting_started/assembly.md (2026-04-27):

# ⚒️ Assembly

<div style="text-align: justify;">

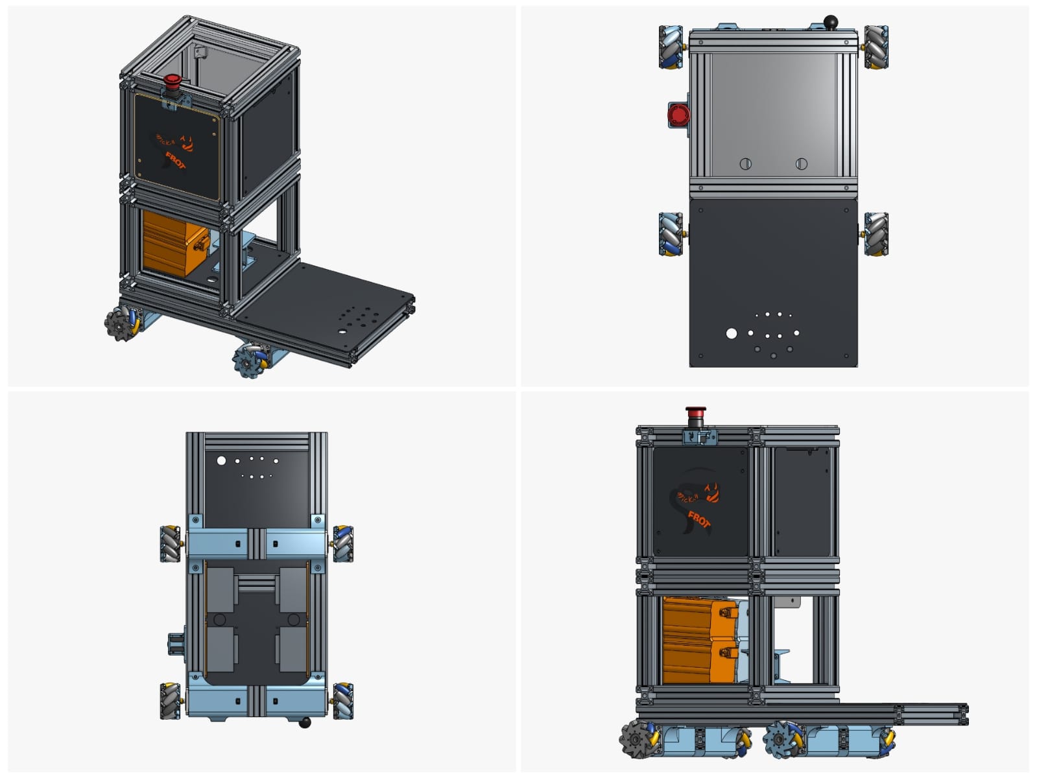
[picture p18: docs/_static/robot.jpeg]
Robot overview


This section describes the assembly process of the MICKY robot, including mechanical construction, PCB fabrication, and electronic integration.

---

## Mechanical Assembly

This section shows the mechanical assembly of the MICKY robot.

<iframe width="800" height="600" 
    src="https://www.youtube.com/embed/L_kPBL3wr8g"
    frameborder="0" 
    allowfullscreen>
</iframe>

---

## Electronics Assembly

This section describes the electrical assembly of the robot, including PCB fabrication, wiring, and integration of electronic components.

### PCB Fabrication

This section describes the process used to manufacture the custom Printed Circuit Boards (PCBs) developed for the MICKY robot. The boards were produced using a low-cost and accessible method, allowing easy replication without specialized equipment.

### Required Materials

- Copper-clad board  
- Photographic paper  
- Ferric chloride solution  
- Any heat-generating surface  
- Permanent marker  

### Fabrication Process

1. **Print the PCB layout**  
   Print the PCB design at a 1:1 scale on photographic paper.

2. **Transfer the layout**  
   Place the printed layout face-down on the copper board.  
   Apply heat and pressure using an iron to transfer the ink onto the copper surface.

3. **Remove the paper**  
   Carefully remove the photographic paper using a gentle stream of water.  

4. **Fix imperfections**  
   Use a permanent marker to correct any broken traces.

5. **Etching process**  
   Submerge the board in ferric chloride solution to remove the exposed copper.

6. **Cleaning and finishing**  
   Clean and sand the board to remove the ink.  
   The PCB is now ready for soldering.

---

### Custom Boards

These custom boards were designed to simplify system integration and ensure reliable power distribution and signal connectivity across the platform. Each board targets a specific subsystem, contributing to a modular and easily maintainable architecture.

#### Arduino Interface Board

- Arduino Mega 2560  
- Capacitor (63 V / 4700 µF)  
- Resistor (3.3 kΩ)  
- 20 A diode  
- XT60 connectors (4x)  
- JST-XH 5-pin connectors (2x)  
- JST-XH 4-pin connectors (2x)  
- JST-XH 2-pin connector  

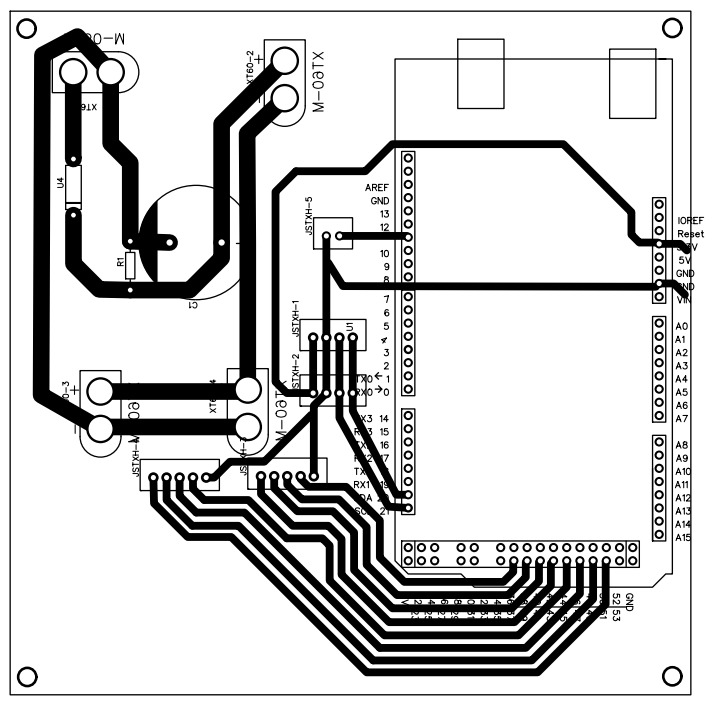
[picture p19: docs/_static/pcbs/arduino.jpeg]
Arduino PCB


---

#### Motor Driver Board

- 20 A diodes (2x)  
- XT60 connectors (3x)  
  - 1x male  
  - 2x female  
- JST-XH 5-pin connector  
- JST-XH 4-pin connectors (2x)  

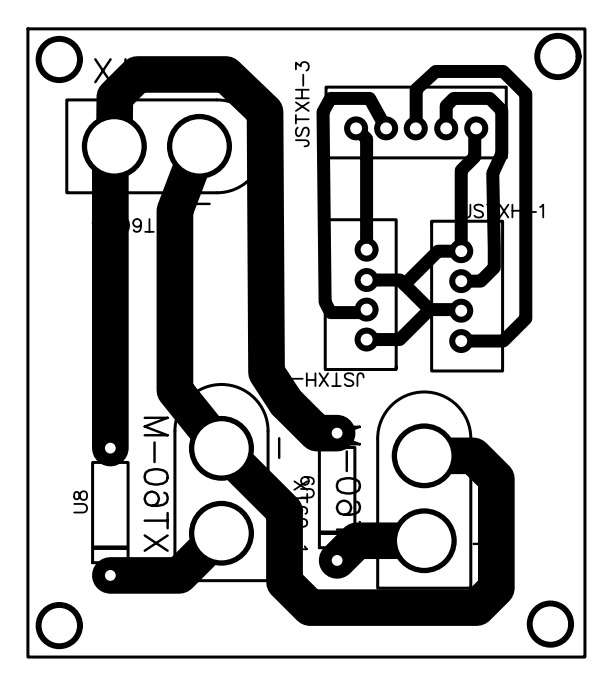
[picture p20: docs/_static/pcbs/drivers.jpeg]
Driver PCB


---

#### IMU Board

- JST-XH 4-pin connector  
- MPU9250 IMU  

<div align="center">
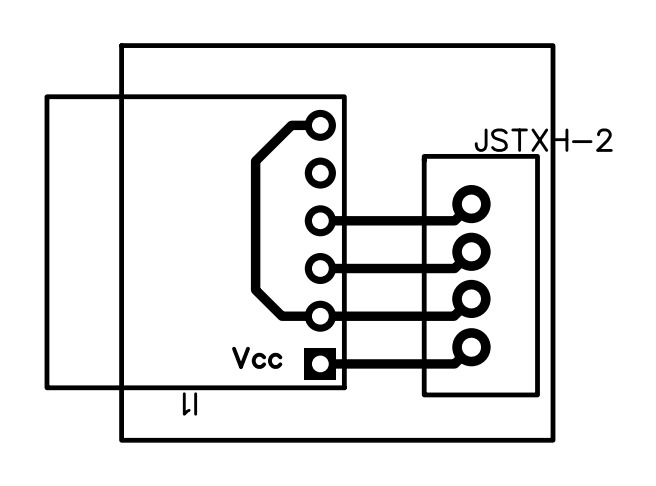
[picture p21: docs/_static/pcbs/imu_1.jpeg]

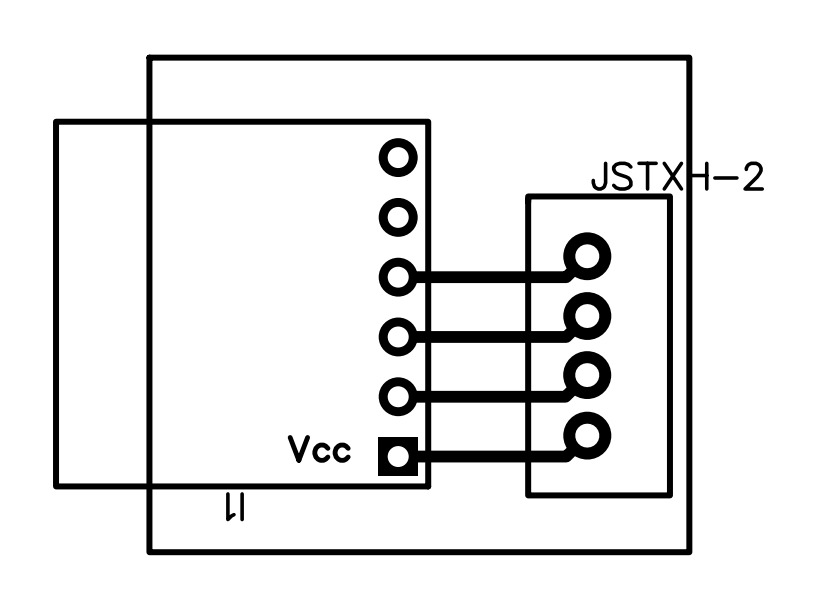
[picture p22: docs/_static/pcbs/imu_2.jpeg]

</div>

To support the use of two IMUs in the system, both PCBs were designed to simplify their integration with the rest of the electronics. However, since both sensors share the same communication bus, it is necessary to differentiate them through I2C addressing.

This is achieved by modifying the AD0 pin configuration: one of the IMU boards includes an external trace connecting the AD0 pin to GND, changing its I2C address, while the other maintains the default internal configuration.

---

```{important}
Ferric chloride is corrosive. Always use protective equipment and work in a ventilated environment.
```

</div>

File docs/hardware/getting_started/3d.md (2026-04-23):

# 🖨️ 3D printing

<div style="text-align: justify;">

This section provides the 3D printable components used in the MICKY robot. All parts were designed to support the mechanical structure and facilitate integration with electronic components, while maintaining low cost and ease of fabrication.

## [Download the 3D Models Here](https://github.com/fbot-research/open_micky/tree/main/hardware)

## Before Printing

> We assume you have basic experience with consumer-level 3D printers (K1 Max, Ender 3, etc.). This means you know how to properly 3D print STL files with PLA filaments and are familiar with reorienting parts, adding supports, adjusting infill, and modifying print speed to achieve your desired balance of material strength, efficiency, and model detail quality.
>

<!-- - For more detailed information, you can check out the 3D printing instructions for [Lekiwi](https://github.com/SIGRobotics-UIUC/LeKiwi/blob/main/3DPrinting.md) and [SO101 Arm](https://github.com/TheRobotStudio/SO-ARM100#printing-the-parts). -->
- All the 3D printed parts shown in the images of MICKY were printed using a **Creality K1 Max with PLA Speed Premium Orange filament**.
- Drying PLA is recommended for humid environments at 45°C for 8 hours before printing.

---

## Wheel Motor Mount

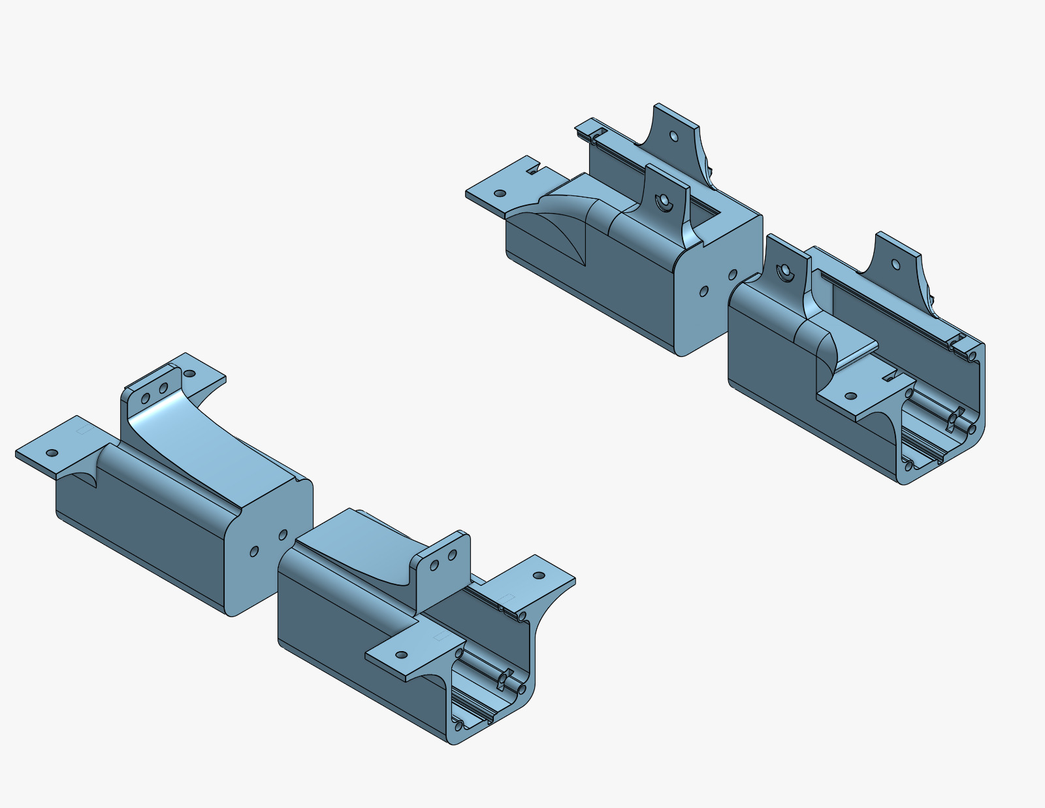
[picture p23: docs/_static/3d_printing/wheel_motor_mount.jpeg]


This component secures the wheel motors to the robot structure, ensuring proper alignment and stability during operation. It is designed to withstand mechanical loads generated by the locomotion system while maintaining ease of installation and replacement. An aluminum profile is placed between each pair of motor mount assemblies to reinforce the structure and improve overall rigidity.

---

## Driver Mount

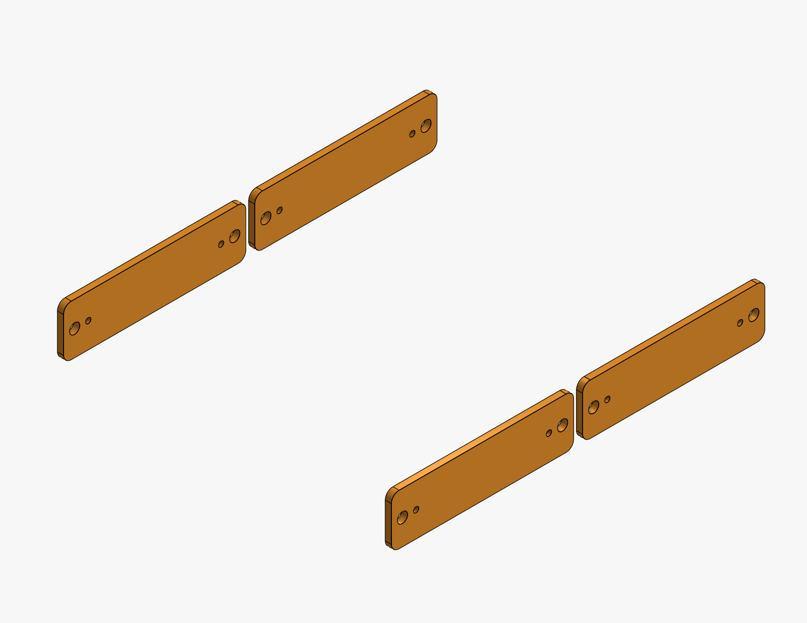
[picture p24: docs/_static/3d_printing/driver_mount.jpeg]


This part provides a dedicated mounting interface for the motor drivers, keeping them securely fixed to the structure. It ensures proper organization and accessibility for wiring and maintenance.

---

## Battery Mount

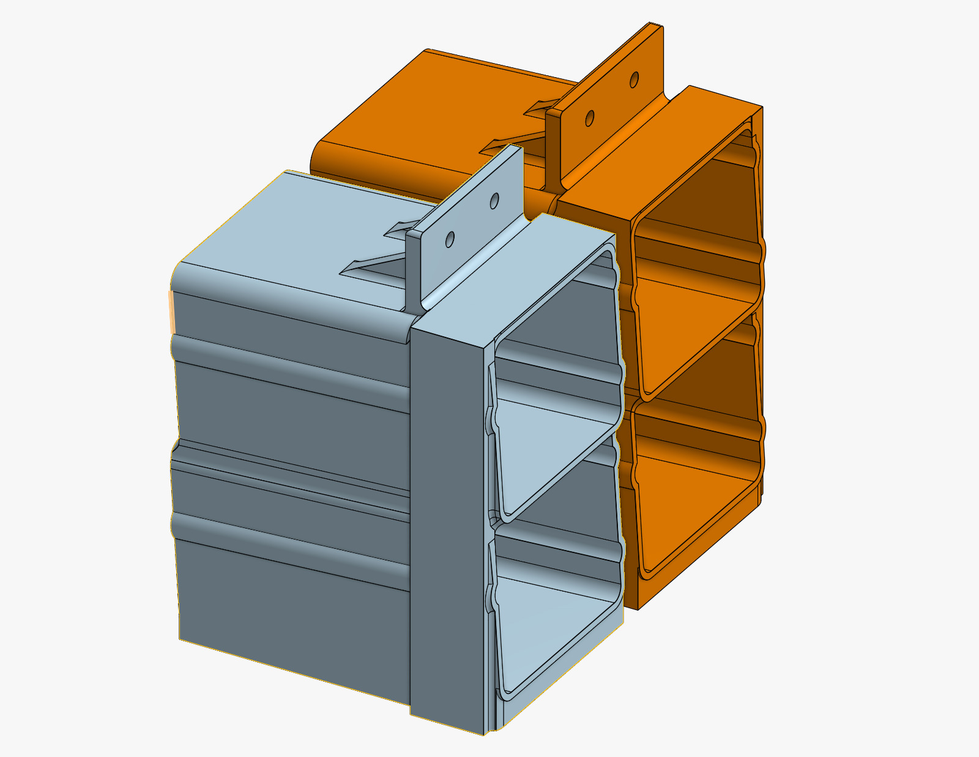
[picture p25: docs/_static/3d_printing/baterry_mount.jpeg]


This component holds the batteries in place, providing structural support and protection during operation. The design ensures stability and easy access for installation and replacement.

```{note}
The robot design provides space for four batteries, with two dedicated exclusively to powering the locomotion system, while the remaining two are intended for use with an external computer, if needed.
```

---

## Arduino Board Mount

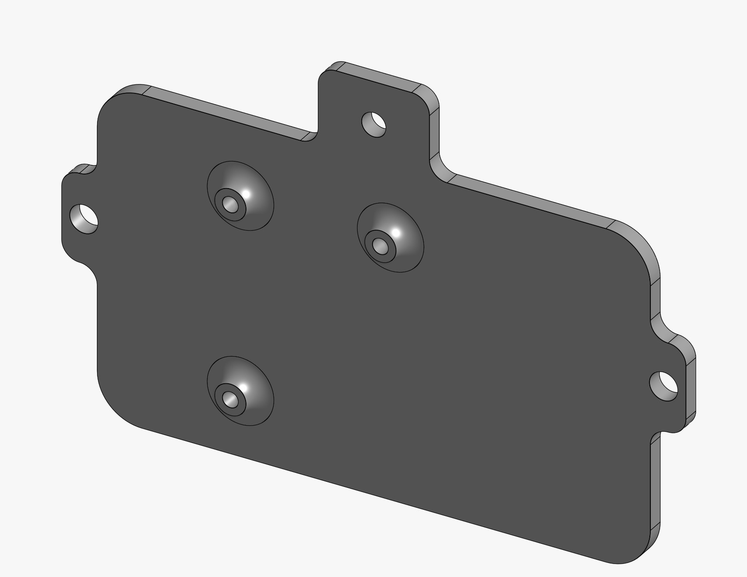
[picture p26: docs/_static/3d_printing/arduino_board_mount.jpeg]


This mount secures the Arduino board to the robot structure, providing a stable platform for control and communication. It is designed to allow easy access to ports and connections.

---

## Driver Board Mount

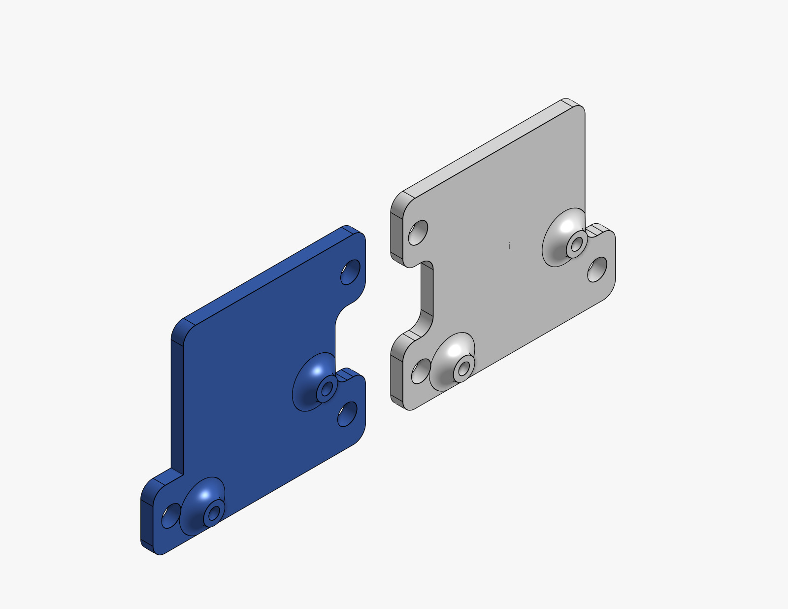
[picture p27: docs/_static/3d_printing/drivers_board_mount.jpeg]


This component is used to mount and organize the driver control boards, ensuring proper positioning and secure fixation. It facilitates cable management and system maintenance.

---

## Structural Supports

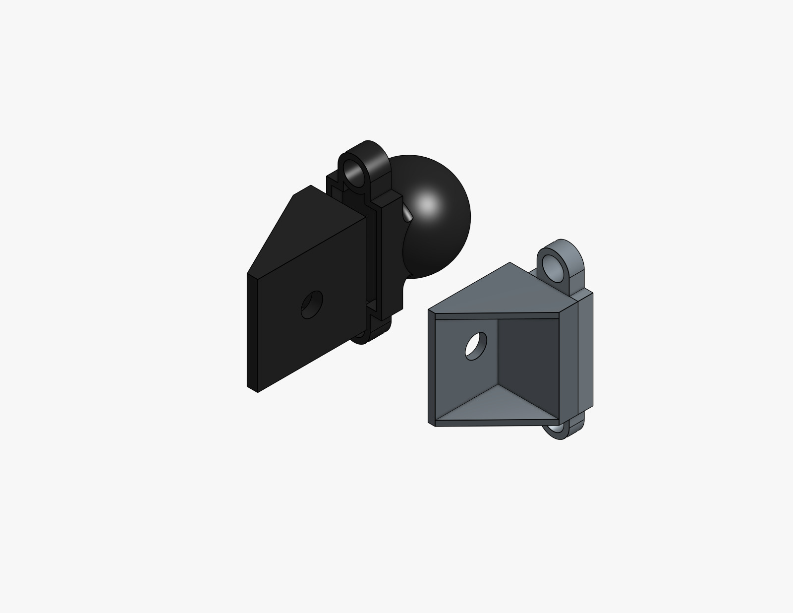
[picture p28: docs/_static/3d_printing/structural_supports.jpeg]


These components reinforce the overall structure of the robot, improving rigidity and mechanical stability. They are designed to distribute loads and maintain alignment between modules.

---

## Emergency Stop Button Mount

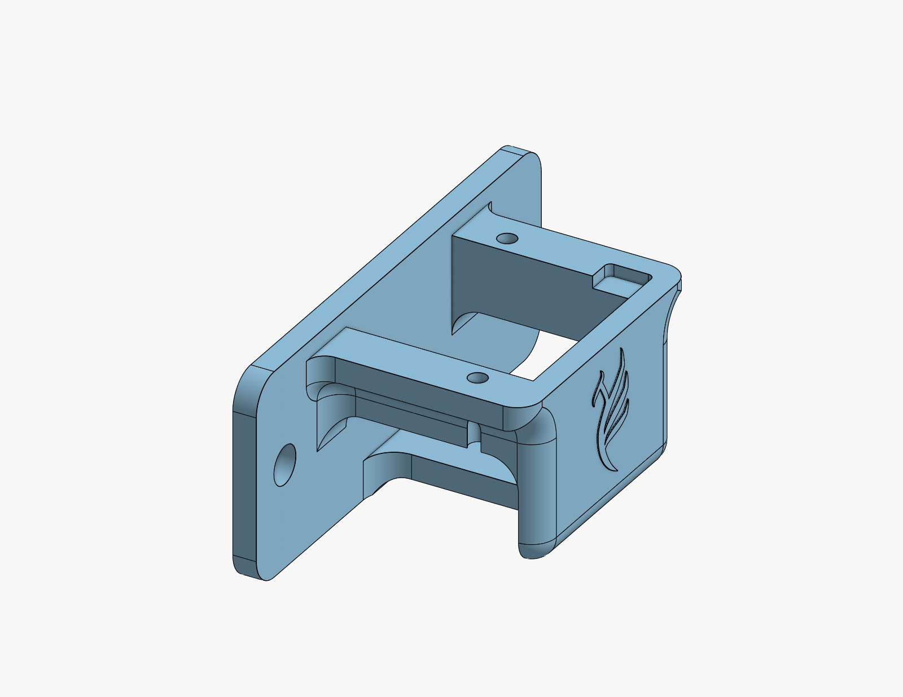
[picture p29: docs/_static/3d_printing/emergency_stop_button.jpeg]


This mount provides a secure interface for installing the emergency stop button, ensuring it remains accessible and firmly fixed. It is positioned to allow quick and reliable user interaction in critical situations.

---

### Cost Considerations

* **Own printer** (Recommended): Everything can be printed on consumer 3D printers like the Creality K1 Max (~$899.00 USD).
* **Filament cost**: Approximately $38–55 USD for the required PLA filament.

</div>

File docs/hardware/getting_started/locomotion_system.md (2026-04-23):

# ⚙️ Locomotion System

<div style="text-align: justify;">

MICKY uses a Mecanum wheel-based locomotion system, enabling omnidirectional motion without requiring rotation of the robot body.

The system adopts a hybrid control architecture, where high-level processing is performed on a computer running **ROS 2 Humble**, while low-level control is handled by dedicated hardware. This separation ensures real-time motor actuation while maintaining flexibility for planning and decision-making.

This design is widely used in mobile robotics applications, providing improved maneuverability, scalability, and system robustness.

---

## Hardware Configuration

Motor control is managed by an **Arduino Mega 2560**, which interfaces with four **TB6600 drivers**. These drivers are responsible for actuating **Nema 23 stepper motors**.

For navigation and state estimation, the robot uses **MPU6050 sensors** connected via the I2C bus.

---

## Robot Kinematics

The robot uses **Mecanum wheels**, enabling omnidirectional motion through the combination of individual wheel velocities.

The system kinematics is based on converting the robot’s velocity commands, defined by the linear velocities in X (`v_x`) and Y (`v_y`), along with the angular velocity (`ω`), into individual wheel velocities.

This allows:

- Forward and backward motion  
- Lateral (sideways) motion  
- Rotation  
- Combined movements (e.g., diagonal motion)  

</div>

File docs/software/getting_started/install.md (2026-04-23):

# ⬇️ Install MICKY

<div style="text-align: justify;">

To install MICKY, follow the commands below.

---

## Requirements

Make sure you have the following installed:

* Ubuntu 22.04
* ROS 2 Humble
* Arduino IDE or PlatformIO
* Gazebo Harmonic (or Garden)

---

## Install MICKY Base Controller

Clone the repository:

```bash
mkdir -p /micky_ws/src && cd micky_ws/src
git clone https://github.com/FBOTWork/micky_base_controller.git
cd micky_base_controller
```

---

## Firmware Setup

Upload the firmware to the Arduino Mega:

1. Open the firmware file:

```bash
firmware_micro_controller/firmware.ino
```

2. Connect the Arduino

3. Configure in Arduino IDE:

* Board: **Arduino Mega 2560**
* Port: `/dev/ttyACM0` or `/dev/ttyUSB0`

4. Click **Upload**

---

## USB Configuration (udev)

Configure a persistent device name for the Arduino.

### Get device information

```bash
udevadm info -a -n /dev/ttyACM0 | grep -E 'idVendor|idProduct|serial'
```

### Create udev rule

```bash
sudo nano /etc/udev/rules.d/99-arduino_robo.rules
```

Add:

```bash
SUBSYSTEM=="tty", ATTRS{idVendor}=="2341", ATTRS{idProduct}=="0043", MODE="0666", SYMLINK+="arduino_robo"
```

### Reload rules

```bash
sudo udevadm control --reload-rules
sudo udevadm trigger
```

### Verify device

```bash
ls /dev/arduino_robo
```

### (Optional) Add user permissions

```bash
sudo usermod -aG dialout $USER
```

Log out and log back in after running this command.

---

## Install MICKY Simulation

Navigate to your workspace source directory and clone the repository:

```bash
cd ~/micky_ws/src
git clone https://github.com/FBOTWork/micky_simulation.git
```

Install rosdep dependencies:

```bash
cd ~/micky_ws
rosdep update
rosdep install --from-paths src --ignore-src -r -y
```

Install required ROS 2 packages:

```bash
sudo apt install -y \
  ros-humble-ros-gz-sim \
  ros-humble-ros-gz-bridge \
  ros-humble-robot-state-publisher \
  ros-humble-slam-toolbox \
  ros-humble-nav2-map-server \
  ros-humble-xacro \
  ros-humble-rviz2
```

---

## Building the Workspace

Run **once** after cloning or modifying package files:

```bash
cd ~/micky_ws
colcon build --symlink-install
source install/setup.bash
```

</div>

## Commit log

2026-04-02 :memo: created bill of material documentation
2026-04-04 :sparkles: added 3D printing section
2026-04-07 :building_construction: added stl files for robot components
    [PCBs_support.stl, battery_case_female_socket_mount.stl, battery_case_lower.stl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]
2026-04-09 :building_construction: added new stl files for robot components
    [arduino_PCB_support.stl, driver_PCB_left_support.stl, driver_PCB_right_support.stl]
2026-04-09 :art: added 3d print images
2026-04-09 :memo: updated 3d and materials documentation
2026-04-10 :memo: updated 3d printing
2026-04-13 :memo: updated material.md
2026-04-14 :memo: updated bom documentation
2026-04-15 :memo: added assembly topic
2026-04-20 :memo: added wheels dollar price
2026-04-21 :memo: added the price in dollars into BoM
2026-04-23 :art: added pcbs images
2026-04-25 :memo: added imu board description
2026-04-26 :memo: added micky assembly video
2026-04-26 :memo: changed mechanical assembly text
2026-04-27 :memo: changed assembly video link
